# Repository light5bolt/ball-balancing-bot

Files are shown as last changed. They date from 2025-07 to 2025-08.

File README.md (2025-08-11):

# Ball Balancing Bot

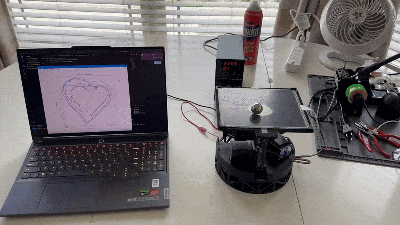
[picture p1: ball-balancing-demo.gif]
Ball Balancing Bot Demo


**A robotics project that uses real-time control and inverse kinematics to keep a ball stable on a movable platform.**

---

## Project Overview

The **Ball Balancing Bot** combines mechanical design, electronics, and control theory to actively stabilize a ball using a 3-degree-of-freedom parallel manipulator.  
It serves as both a hands-on robotics challenge and a learning platform for inverse kinematics, sensor integration, and feedback control.

If you want to see the full build process, circuit assembly, and code integration, check out the **Instructables tutorial**:  
[**DIY Ball Balancer Robot! : 6 Steps with Pictures (with Pictures)**](https://www.instructables.com/Lets-Make-a-Ball-Balancer-Robot/)

---

## Repository Contents

- **`BallBalancingBot/`** – Core control implementation (C++).
- **`CAD Files and STLs/`** – 3D printable and editable CAD files for the mechanical frame.
- **`Python Plotters/`** – Scripts for plotting system performance and visualizing motion data.
- **`Ball Balancing Robot Circuit Documentation.pdf`** – Detailed circuit diagrams and wiring instructions.
- **`Ball Balancing Robot IK Derivation.pdf`** – Full symbolic derivation of the inverse kinematics equations.
- **`circuit_image.png`** – Quick reference circuit schematic.

---

## Features

- Complete inverse kinematics derivation for a 3-RRS parallel manipulator.
- Modular CAD/STL files for easy reproduction and modification.
- Circuit documentation with clear wiring diagrams.
- Python visualization tools for trajectory and control analysis.

---

## Project Structure

ball-balancing-bot/
│
├── BallBalancingBot/ # Core control implementation

├── CAD Files and STLs/ # Mechanical component models

├── Python Plotters/ # Visualization scripts

├── Ball Balancing Robot Circuit Documentation.pdf

├── Ball Balancing Robot IK Derivation.pdf

├── circuit_image.png

└── README.md

---

## License

This work is licensed under the **Creative Commons Attribution-NonCommercial-ShareAlike 4.0 International License**.  
You are free to share and adapt the material for non-commercial purposes, as long as you give appropriate credit and distribute your contributions under the same license.



---

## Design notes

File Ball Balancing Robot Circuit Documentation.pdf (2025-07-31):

# Circuit Documentation

## Summary

This circuit is designed to control multiple bipolar stepper motors using TMC2208 stepper motor drivers, a Teensy 4.0 microcontroller, and a resistive touch screen interface. The circuit is powered by a 48V power supply, which is stepped down to 5V for the Teensy and other components. The TMC2208 drivers are used to control the stepper motors, and the Teensy microcontroller is responsible for sending control signals to the drivers and interfacing with the touch screen.

## Component List

1. TMC2208 Stepper Motor Driver
- Description: A stepper motor driver used to control bipolar stepper motors.
- Pins: GND, VIO, M2B, M2A, M1A, M1B, VM, DIR, STEP, CLK, PDN, NC, MS2, MS1, EN
2. Power Supply
- Description: Provides power to the circuit.
- Pins: +, -
3. Bipolar Stepper Motor (NEMA 17)
- Description: A type of stepper motor used for precise control of motion.
- Pins: A-, A+, B+, B-
4. Electrolytic Capacitor
- Description: Used for filtering and stabilizing voltage.
- Pins: -, +
- Properties: Capacitance: 0.0001 Farads
5. Teensy 4.0 Microcontroller
- Description: A microcontroller used for processing and control tasks.
- Pins: 5V, GND, 3V, 23, 22, 21, 20, 19, 18, 17, 16, 15, 14, 13, 12, 11, 10, 9, 8, 7, 6, 5, 4, 3, 2, 1, 0
6. 48V to 5V Converter
- Description: Steps down voltage from 48V to 5V.
- Pins: out+, out--, in+, in--
7. Rocker Switch
- Description: A switch used to control the power supply.
- Pins: 1, 2
8. Resistive Touch Screen
- Description: A touch screen interface for user input.
- Pins: 1, 2, 3, 4

## Wiring Details

### TMC2208 Stepper Motor Driver

- VM Pin: Connected to the positive terminal of the electrolytic capacitors and the 48V to 5V converter's in+ pin.
- GND Pin: Connected to the negative terminal of the electrolytic capacitors, the 48V to 5V converter's in-- pin, and the Teensy 4.0's GND pin.
- VIO, MS2, MS1 Pins: Connected to the Teensy 4.0's 3V pin.
- EN Pin: Connected to the Teensy 4.0's pin 0.
- STEP Pin: Connected to the Teensy 4.0's pins 1, 3, and 5 for different instances.
- DIR Pin: Connected to the Teensy 4.0's pins 2, 4, and 6 for different instances.

### Power Supply

- + Pin: Connected to the Rocker Switch's pin 2.
- - Pin: Connected to the 48V to 5V converter's in-- pin.

### Bipolar Stepper Motor (NEMA 17)

- A+, A-, B+, B- Pins: Connected to the corresponding M1A, M1B, M2A, M2B pins on the TMC2208 drivers.

### Electrolytic Capacitor

- + Pin: Connected to the VM pin of the TMC2208 drivers and the 48V to 5V converter's in+ pin.
- - Pin: Connected to the GND pin of the TMC2208 drivers and the 48V to 5V converter's in-- pin.

### Teensy 4.0 Microcontroller

- 5V Pin: Connected to the 48V to 5V converter's out+ pin.
- GND Pin: Connected to the 48V to 5V converter's out-- pin and the GND pin of the TMC2208 drivers.
- 3V Pin: Connected to the VIO, MS2, and MS1 pins of the TMC2208 drivers.
- Pins 0-6: Used for control signals to the TMC2208 drivers.

### 48V to 5V Converter

- in+ Pin: Connected to the Rocker Switch's pin 1.
- in-- Pin: Connected to the GND pin of the TMC2208 drivers and the Power Supply's - pin.
- out+ Pin: Connected to the Teensy 4.0's 5V pin.

- out-- Pin: Connected to the Teensy 4.0's GND pin.

### Rocker Switch

- Pin 1: Connected to the 48V to 5V converter's in+ pin.
- Pin 2: Connected to the Power Supply's + pin.

### Resistive Touch Screen

- Pins 1-4: Connected to the Teensy 4.0's pins 14-17 for touch input.

## Code Documentation

Refer to https://github.com/skulkarni3000/ball-balancing-bot

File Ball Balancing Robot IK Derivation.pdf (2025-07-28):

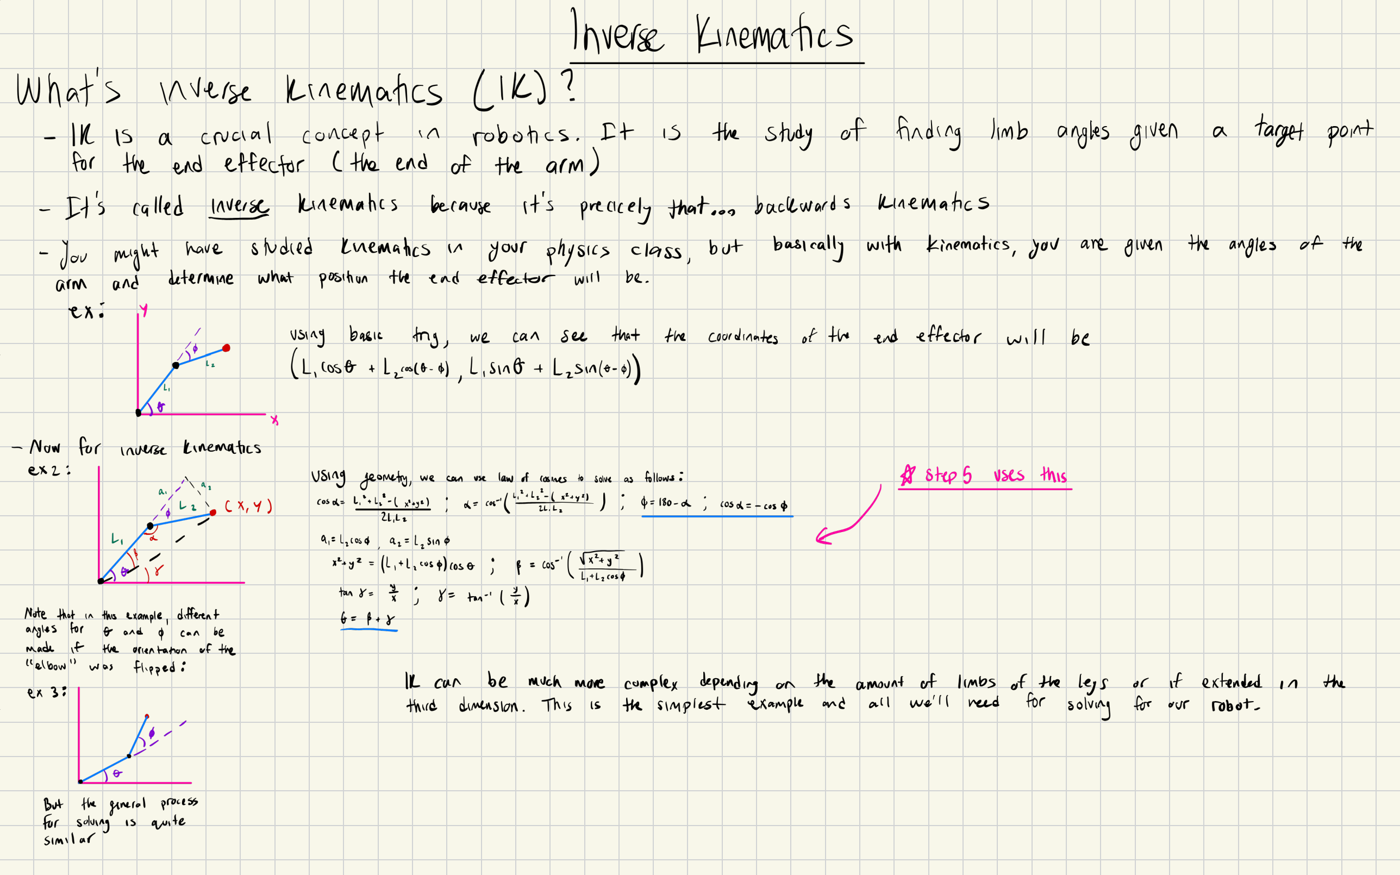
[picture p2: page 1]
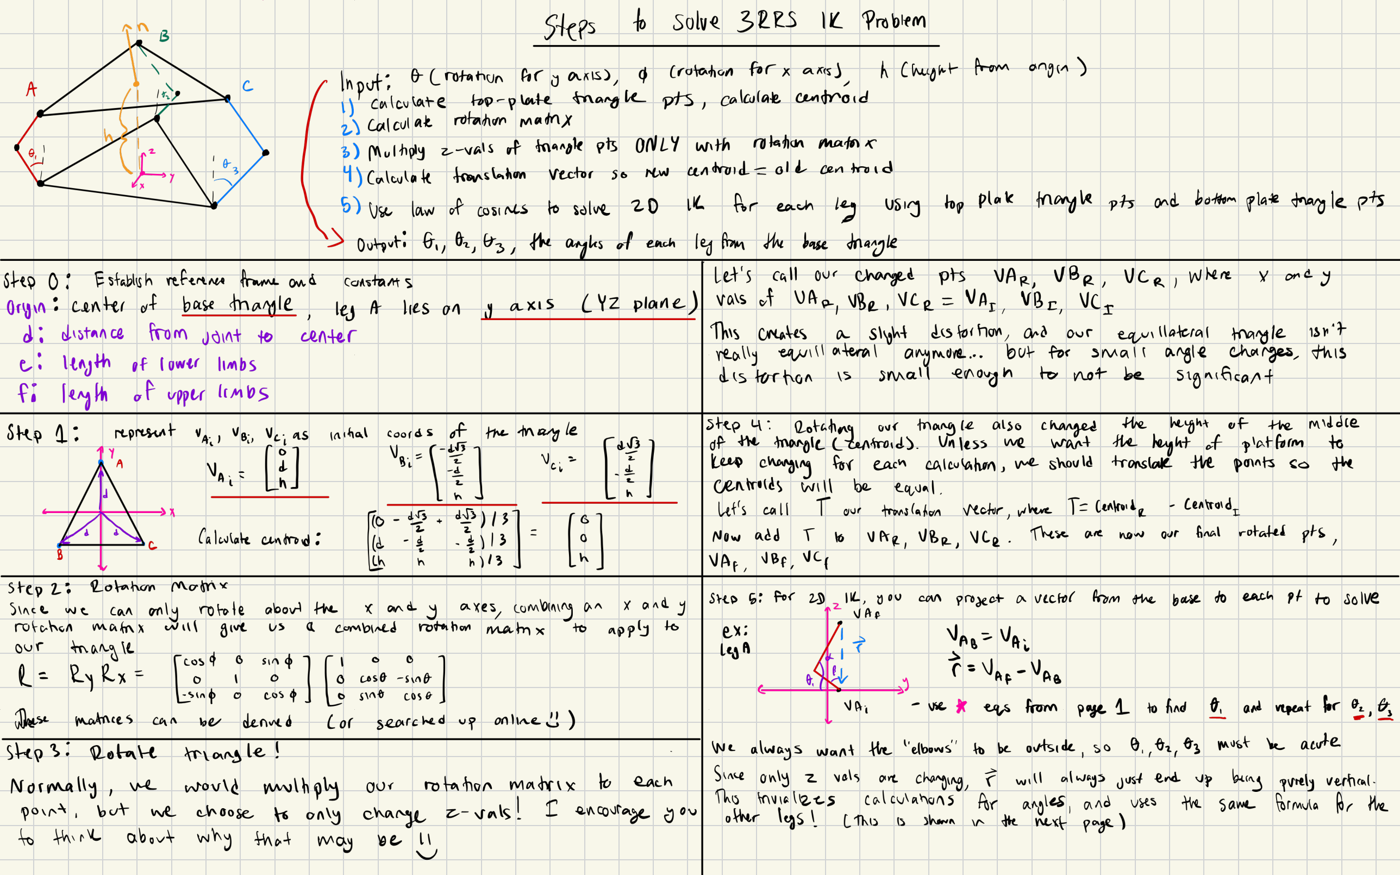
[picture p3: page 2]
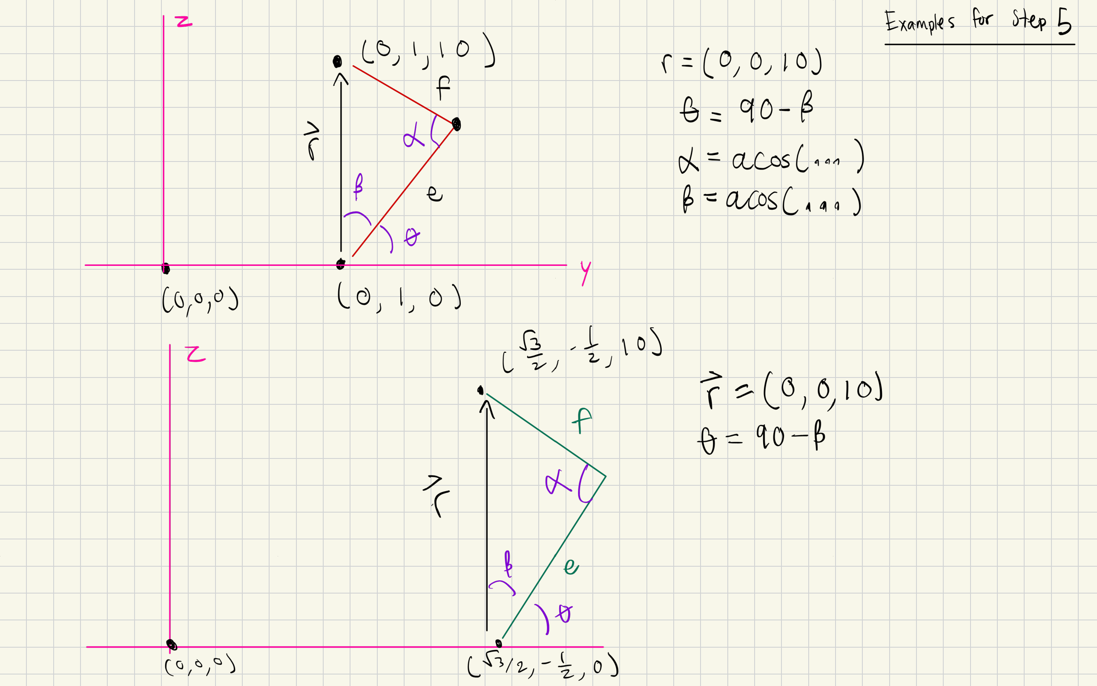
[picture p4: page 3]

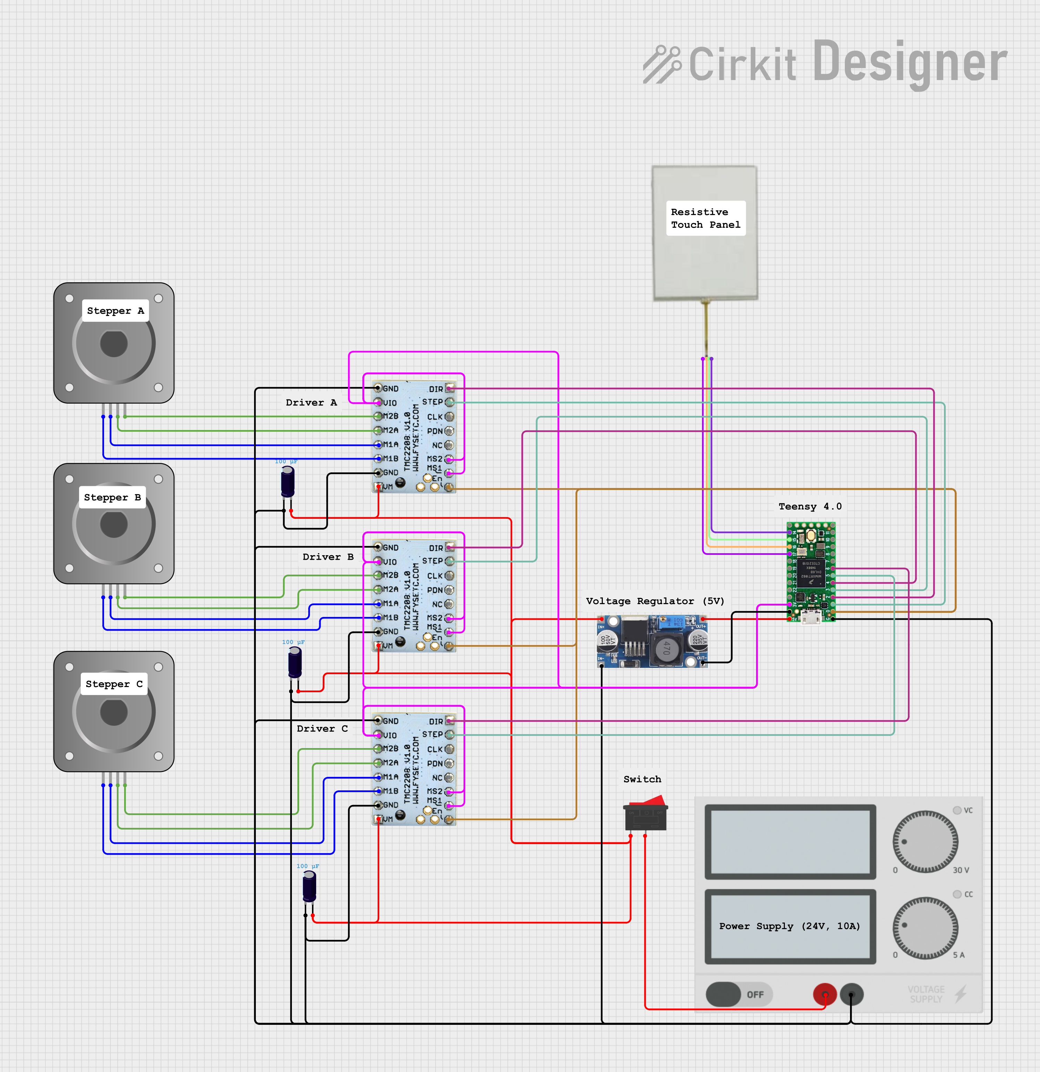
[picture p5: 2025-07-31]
circuit_image.png

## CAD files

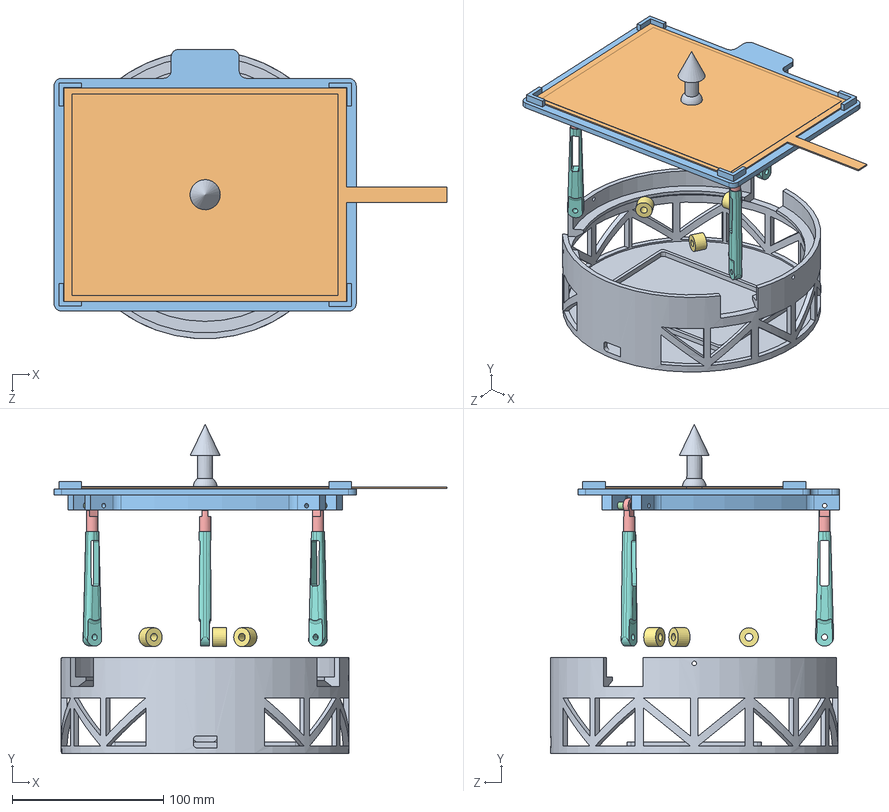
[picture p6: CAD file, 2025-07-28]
CAD Files and STLs/Robot Full Assem.SLDASM
260.0 x 217.9 x 191.5 mm
RobotBase
UpperLimb x 3
Shaft Spacer x 3
TieRod Ball x 3
TieRod Base x 3
M3 Spacer x 6
ScreenPlate
LCD Screen
NormalVector

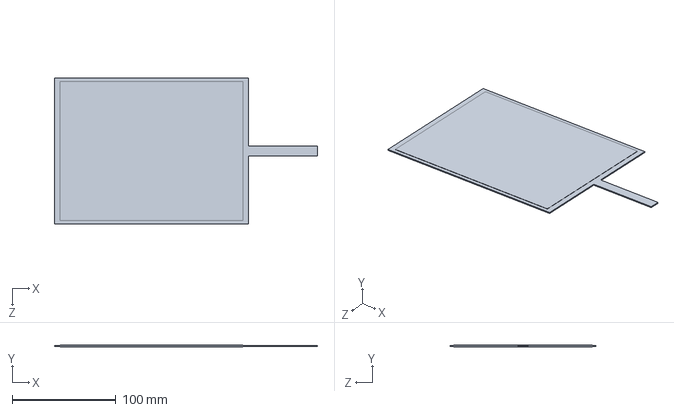
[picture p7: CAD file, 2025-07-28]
CAD Files and STLs/Parts/LCD Screen.SLDPRT
253.5 x 1.58 x 141.0 mm

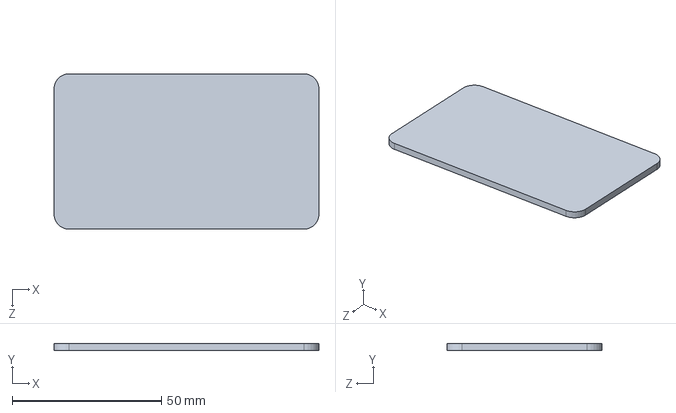
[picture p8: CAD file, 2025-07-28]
CAD Files and STLs/Parts/BreadboardPlaceholder.SLDPRT
88.9 x 2.50 x 52.1 mm

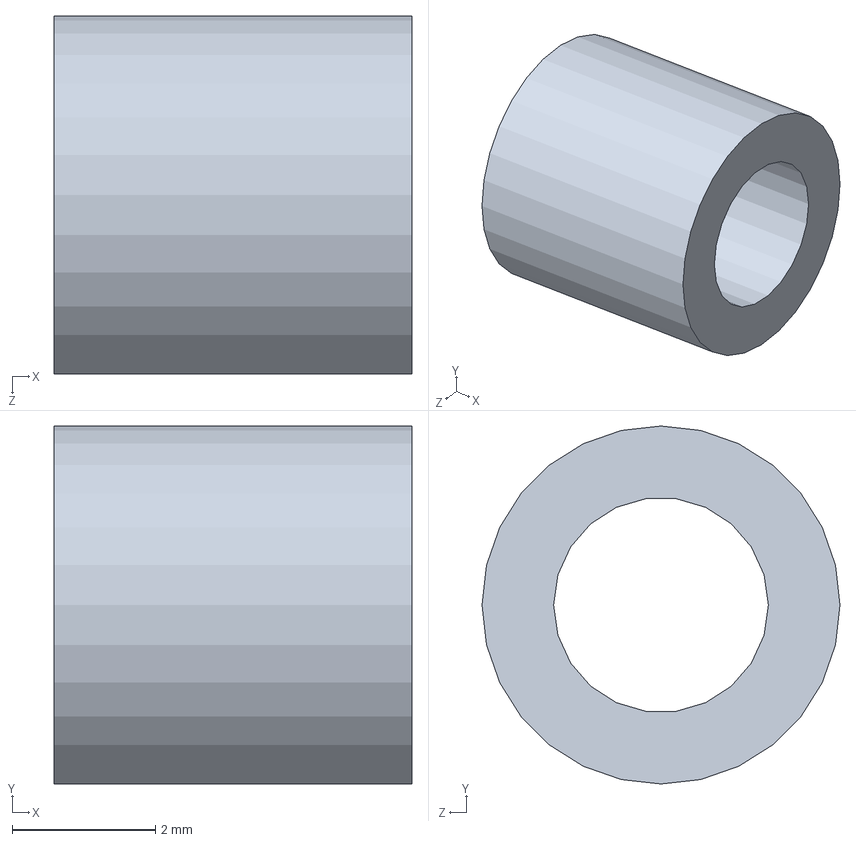
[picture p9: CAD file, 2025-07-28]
CAD Files and STLs/Parts/M3 Spacer.SLDPRT
5.00 x 5.00 x 5.00 mm

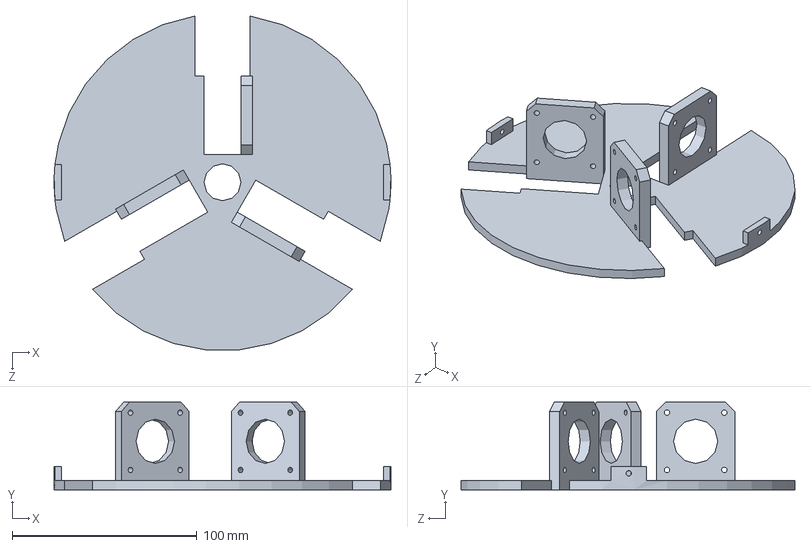
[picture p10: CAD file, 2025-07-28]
CAD Files and STLs/Parts/MotorPlate.SLDPRT
182.3 x 47.5 x 180.6 mm

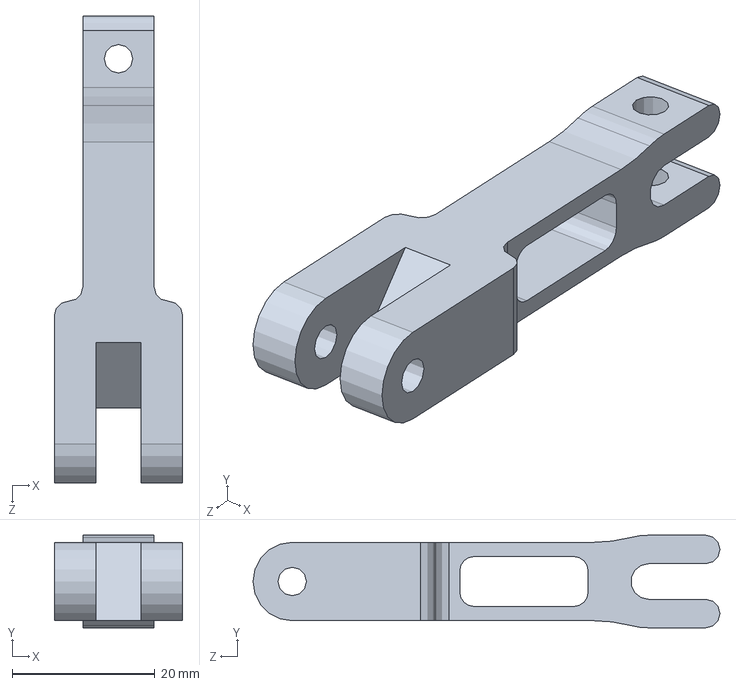
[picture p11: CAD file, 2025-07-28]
CAD Files and STLs/Parts/LowerLimb.SLDPRT
18.0 x 13.0 x 65.5 mm

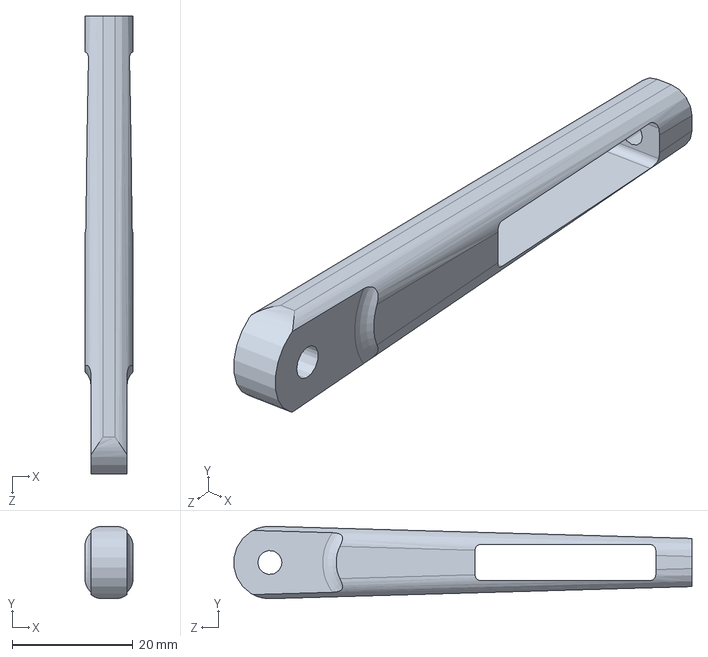
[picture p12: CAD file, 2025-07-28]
CAD Files and STLs/Parts/UpperLimb.SLDPRT
8.00 x 12.0 x 75.9 mm

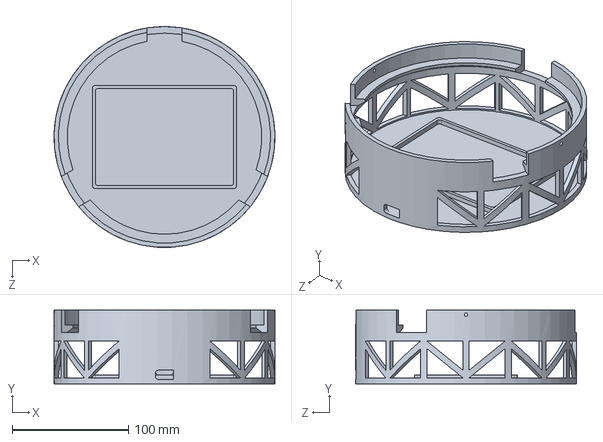
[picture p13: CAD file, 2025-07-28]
CAD Files and STLs/Parts/RobotBase.SLDPRT
190.5 x 63.5 x 190.5 mm

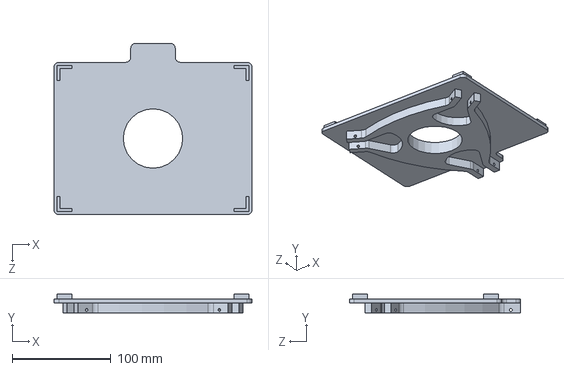
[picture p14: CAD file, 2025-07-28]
CAD Files and STLs/Parts/ScreenPlate.SLDPRT
200.0 x 19.0 x 173.2 mm

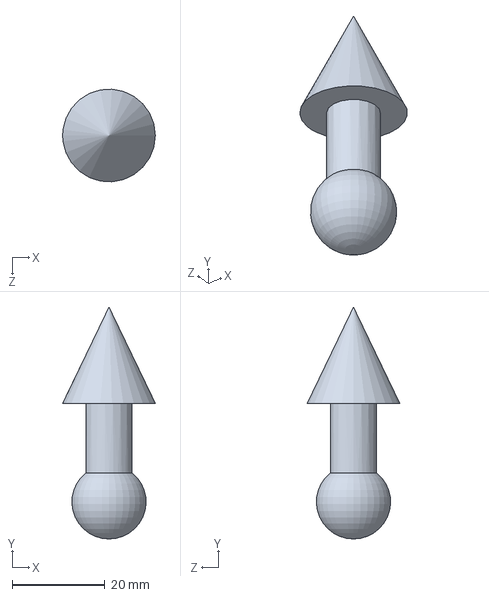
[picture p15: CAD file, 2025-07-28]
CAD Files and STLs/Parts/NormalVector.SLDPRT
20.0 x 50.0 x 20.0 mm

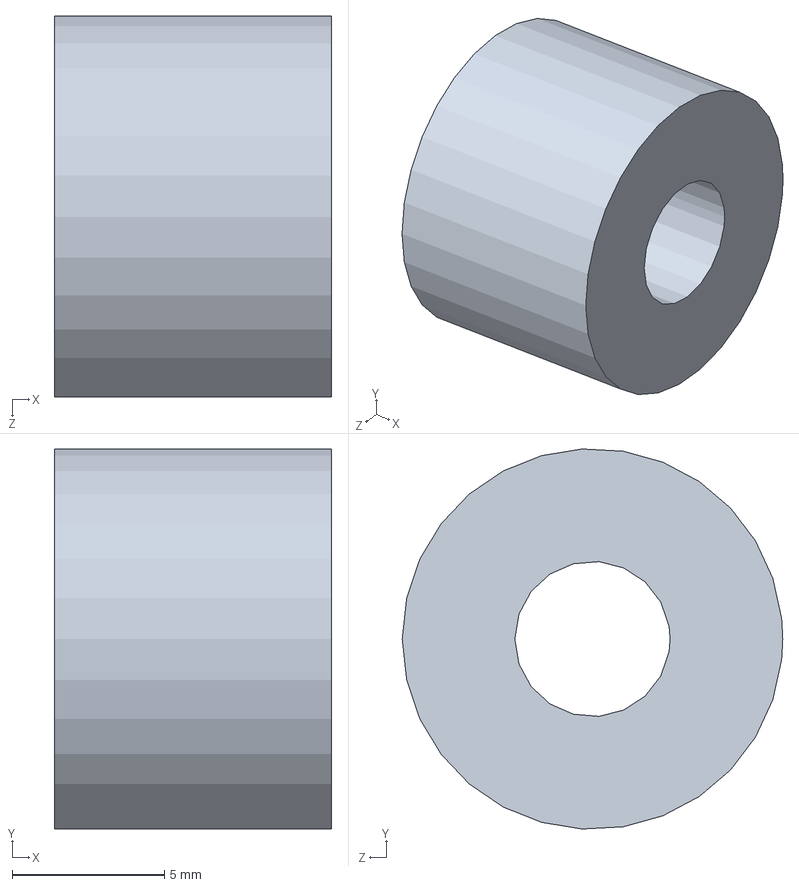
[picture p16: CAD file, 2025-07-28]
CAD Files and STLs/Parts/Shaft Spacer.SLDPRT
9.10 x 12.5 x 12.5 mm

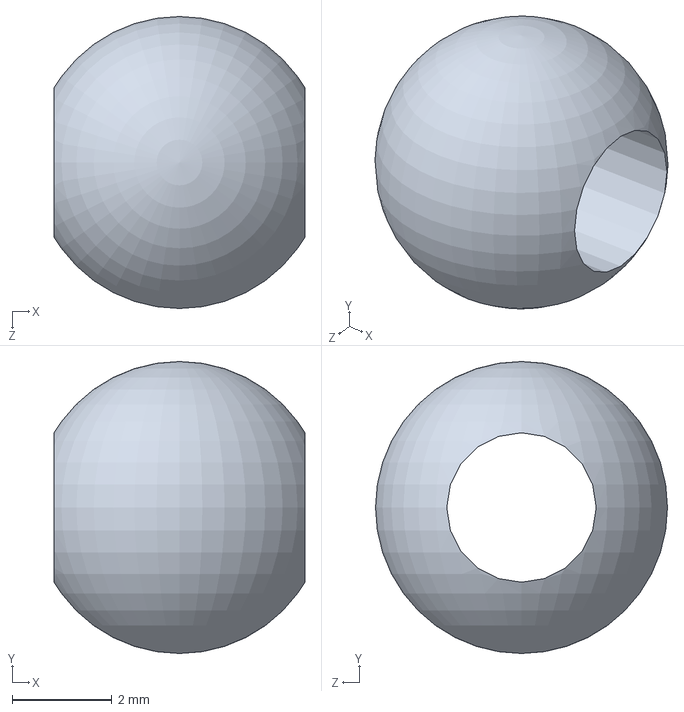
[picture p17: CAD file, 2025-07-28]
CAD Files and STLs/Parts/TieRod Ball.SLDPRT
5.03 x 5.86 x 5.86 mm

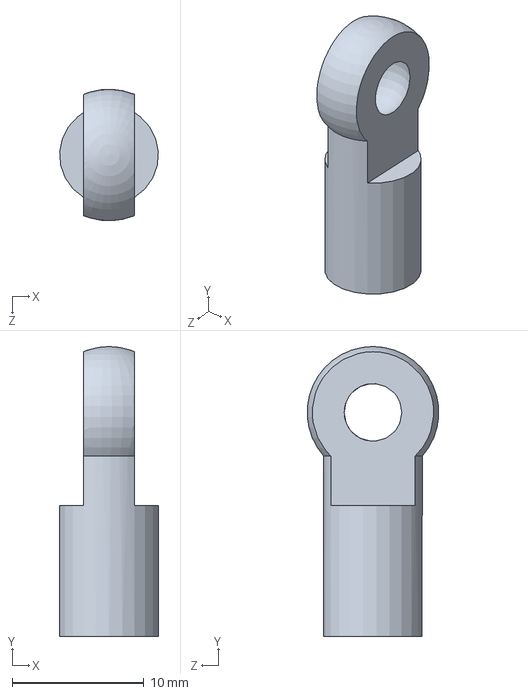
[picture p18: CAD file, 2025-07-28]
CAD Files and STLs/Parts/TieRod Base.SLDPRT
7.48 x 22.0 x 9.97 mm

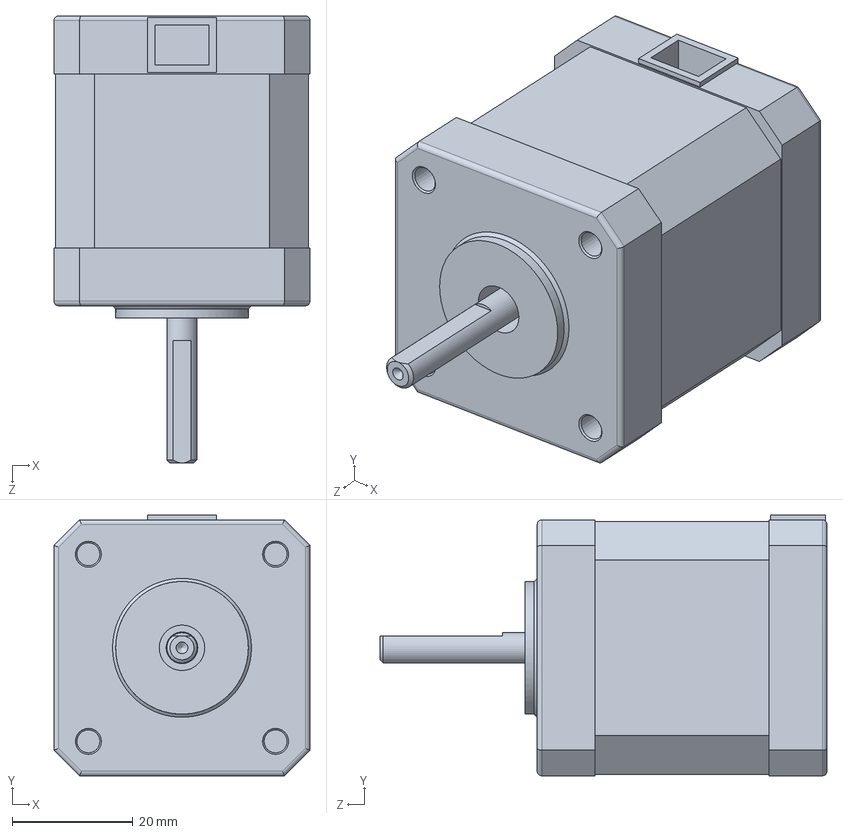
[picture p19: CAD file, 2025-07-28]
CAD Files and STLs/Parts/StepperMotor.SLDPRT
42.4 x 43.2 x 74.0 mm

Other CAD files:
CAD Files and STLs/STLs/LowerLimb.STL
CAD Files and STLs/STLs/MotorPlate.STL
CAD Files and STLs/STLs/RobotBase.STL
CAD Files and STLs/STLs/ScreenPlate.STL
CAD Files and STLs/STLs/ShaftSpacer.STL
CAD Files and STLs/STLs/UpperLimb.STL

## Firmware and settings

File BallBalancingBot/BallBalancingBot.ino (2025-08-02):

#include <Arduino.h>
#include "InverseKinematics.h"
#include "MotorControl.h"
#include "Screen.h"
#include "PIDControllers.h"


// Global variable declaration
bool enable_serial_output = true;

// Function definitions
void muteAllSerialOutput() {
  enable_serial_output = false;
}

void enableAllSerialOutput() {
  enable_serial_output = true;
}


void setup() {
  // Initialization functions
  Serial.begin(115200);
  muteAllSerialOutput();
  if (enable_serial_output) Serial.println("----------------NEW RUN-----------------"); 
  screen_init();
  motor_init();
  home_motors();
  go_home();
  delay(1000);

  // Headers for CSV file reading
  //Serial.println("Time(ms),Ball_X(mm),Ball_Y(mm),Target_X(mm),Target_Y(mm)");
}

void loop() {
  pid_balance(0,0);
  //move_ellipse(30, 20, 20, 4);
  //move_figure8(30, 20, 4);
  //move_square(30, 20, 4);
  //move_heart(40, 20, 4);
}

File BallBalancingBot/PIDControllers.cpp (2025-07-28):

#include <Arduino.h>
#include <math.h>
#include "PIDControllers.h"

extern bool enable_serial_output;

// PID Constants
#define kp .8            //.8
#define ki .2            //.2
#define kd .09           //.09
#define kv 0.05          //.05
#define kp_adj .4        //.4
#define ki_adj .25       //.25
#define kd_adj .23       //.23
#define max_output 83.5  // max X distance away from the center
#define max_angle 12.5   // max tilt angle

//Variables needed for PID control
double error[2] = { 0, 0 }, error_prev[2], integ[2] = { 0, 0 }, deriv[2] = { 0, 0 }, output[2], output_angles[2];
double speed[3] = { 0, 0, 0 }, speed_prev[3];

// variables for velocity damping
double ball_vel[2] = { 0, 0 }, p_prev[2] = { 0, 0 };
double predict_time = 0.3;

//Runs X and Y PID Controllers to balance ball at a specific point.
void pid_balance(double setpoint_x, double setpoint_y) {

  static unsigned long t_prev = 0;              // Records previous time (uses static so the variable gets remembered through each loop iteration)
  static unsigned long last_detected_time = 0;  // Track when ball was last detected
  unsigned long t = millis();                   // Records current time using millis() (which counts total time since the program started)
  double dt = (t - t_prev) / 1000.0;            // Converts milliseconds to seconds

  // Handles first run or unreasonable time gaps
  if (t_prev == 0 || dt > .075) {
    t_prev = t;
    //Serial.println((String) "dt: " + dt + ". Time gap too large or first run. Resetting timing.");
    return;  // Ends function
  }

  // Only runs if minimum sample time has passed (0.01 seconds or 10 milliseconds)
  if (dt >= 0.01) {
    bool detected = check_detected();  //checks if ball is detected
    coords p = get_coords();           // retrieves ball's position


    if (detected) {
      last_detected_time = t;

      // Output data for plotting (every 10th iteration to avoid overwhelming)
      static int plot_counter = 0;
      if (plot_counter % 10 == 0 && !enable_serial_output) {

        // CSV format: Timestamp, Ball_X, Ball_Y, Target_X, Target_Y
        Serial.print(millis());
        Serial.print(",");
        Serial.print(p.x_mm, 3);  // 3 decimal places
        Serial.print(",");
        Serial.print(p.y_mm, 3);
        Serial.print(",");
        Serial.print(setpoint_x, 3);
        Serial.print(",");
        Serial.println(setpoint_y, 3);
      }
      plot_counter++;

      // Calculate velocity
      ball_vel[0] = (p.y_mm - p_prev[0]) / (dt * 50);
      ball_vel[1] = (p.x_mm - p_prev[1]) / (dt * 50);
      p_prev[0] = p.y_mm;
      p_prev[1] = p.x_mm;

      // Calculates PID values and send output to motors
      for (int i = 0; i < 2; i++) {

        error_prev[i] = error[i];
        double error_current = (i == 0) ? (p.y_mm - setpoint_y) : (p.x_mm - setpoint_x);  //Calculates error based on ball position
        double v = constrain(ball_vel[i], -1000, 1000);
        error[i] = error_current;
        integ[i] += error[i] * dt;
        integ[i] = constrain(integ[i], -50, 50);  // Constrains integral values to prevent windup
        deriv[i] = (error[i] - error_prev[i]) / dt;
        deriv[i] = isnan(deriv[i]) || isinf(deriv[i]) ? 0 : deriv[i];  // Simple check to eliminate nonreal or infinite numbers, as derivative is being divided by a number that could be zero

        // Adjusts gain constants if ball is close to target
        if (abs(error[i]) < 25) {
          output[i] = kp_adj * error[i] + ki_adj * integ[i] + kd_adj * deriv[i];
        } else {
          output[i] = kp * error[i] + ki * integ[i] + kd * deriv[i];
        }
        output_angles[i] = constrain(output[i], -max_output, max_output) * (max_angle / max_output);  // scales down PID output and maps it to an angle
      }

      // calculates requires speeds for each motors
      speed_controller(speed);

      // for each calculated PID value, run the move command for 20ms
      unsigned long move_start = millis();
      while (millis() - move_start < 20) {
        move_to_angle(output_angles[0], -output_angles[1], 80, speed);
      }

      // Prints PID angle outputs if desired
      if (enable_serial_output) Serial.println((String) "X angle: " + output_angles[1] + ". Y angle: " + output_angles[0] + ". Speed of motor A: " + speed[0]);
    }

    else {
      // Check if ball has been undetected for 3 seconds (3000 milliseconds)
      if (t - last_detected_time >= 3000) {
        integ[0] = integ[1] = 0;         // Reset integral terms after 3 seconds
        move_to_angle(0, 0, 80, speed);  // Goes back to home
      }

      //waits and checks again if ball is detected (eliminates error from input)
      delay(10);
      detected = check_detected();
      if (!detected) {
        //Serial.println("Ball not detected!");
        return;  // exits current iteration
      }
    }
    t_prev = t;  // resets value of t_prev
  }
}

//uses the PID controller to move the ball to a point for a specified amount of time (in milliseconds)
void move_to_point(double setpoint_x, double setpoint_y, unsigned long delay) {
  unsigned long t_prev = millis();
  if (enable_serial_output) Serial.println((String) "Moving to pt: ( " + setpoint_x + " , " + setpoint_y + " )");
  while (millis() - t_prev < delay) {
    pid_balance(setpoint_x, setpoint_y);
  }
}

// moves in a line pattern. rx and ry are distance from endpoint to center (0-80). speed: (10-50 ms). repeat: num of times (0 = infinite loop)
void move_line(double rx, double ry, double speed, int repeat) {
  int cycles = (repeat == 0) ? 9999 : repeat;

  move_to_point(-rx, -ry, 2000);  // moves to start point
  // move from points (-rx, -ry) to (rx, ry)
  for (int i = 0; i < cycles; i++) {
    // calculate amount of intermediate steps
    double steps = 100;
    double steps_x = (2 * rx) / steps;
    double steps_y = (2 * ry) / steps;

    // forward direction
    for (int j = 0; j <= steps; j++) {
      double x = -rx + (j * steps_x);
      double y = -ry + (j * steps_y);
      move_to_point(x, y, speed);
    }

    // backwards direction
    for (int j = steps; j >= 0; j--) {
      double x = -rx + (j * steps_x);
      double y = -ry + (j * steps_y);
      move_to_point(x, y, speed);
    }
  }
  Serial.println("---------------Line pattern finished--------------");
}
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

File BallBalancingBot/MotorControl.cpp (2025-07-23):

#include "MotorControl.h"

#define ANGLE_TO_ORIGIN_A 71     // angle offset
#define ANGLE_TO_ORIGIN_B 66.75  // angle offset
#define ANGLE_TO_ORIGIN_C 61.95  // angle offset
#define ENA 0                    // ENA pin
#define h0 87                    // height of platform when motors are at zero position
#define ks 100.0                 // a constant to change our proportional speed function

// setup for steppers
AccelStepper motorA(1, 3, 2);  //(driver type, STEP, DIR) Driver A
AccelStepper motorB(1, 5, 4);  //(driver type, STEP, DIR) Driver B
AccelStepper motorC(1, 7, 6);  //(driver type, STEP, DIR) Driver C
MultiStepper motors;           // Create instance of MultiStepper

long int pos[3];              // stores positions of stepper motors
extern double speed[3];       // an initialization of the stepper motor speeds
extern double speed_prev[3];  // an array to store previous speeds which we use later to change speed proportionally

//initializes motors by adding them in multistepper class
void motor_init() {
  motors.addStepper(motorA);
  motors.addStepper(motorB);
  motors.addStepper(motorC);
  pinMode(ENA, OUTPUT);
  digitalWrite(ENA, HIGH);
  delay(2000);
  digitalWrite(ENA, LOW);
}

// angle in degrees to the nearest step (rounds up)
long int angle_to_steps(double angle) {
  return round((3200 / 360) * angle);
}

//steps to nearest angle (as a decimal)
double steps_to_angle(int steps) {
  return (360 / 3200) * steps;
}

//moves motors to position where bottom leg is parallel to the ground. this is the zero position
void home_motors() {
  motorA.setMaxSpeed(1000);
  motorB.setMaxSpeed(1000);
  motorC.setMaxSpeed(1000);

  pos[0] = angle_to_steps(ANGLE_TO_ORIGIN_A);
  pos[1] = angle_to_steps(ANGLE_TO_ORIGIN_B);
  pos[2] = angle_to_steps(ANGLE_TO_ORIGIN_C);

  //calculates position and moves all motors to the zero position
  motors.moveTo(pos);
  motors.runSpeedToPosition();

  //makes the new point the origin (zero position)
  motorA.setCurrentPosition(0);
  motorB.setCurrentPosition(0);
  motorC.setCurrentPosition(0);

  //Serial.println("Motors to zero position");
}

//goes to zero position (home). requires home_motors first.
void go_home() {
  for (int i = 0; i < 3; i++) pos[i] = 0;
  motors.moveTo(pos);
  motors.runSpeedToPosition();
}

// calculates positions to move to a specific angle, but only moves at most one step per call.
void move_to_angle(double theta_deg, double phi_deg, double h, double speed[3]) {

  //uses get_angles function to get positions required to move to position
  CalculatedAngles result = get_angles(theta_deg, phi_deg, h);
  pos[0] = angle_to_steps(result.thetaA);
  pos[1] = angle_to_steps(result.thetaB);
  pos[2] = angle_to_steps(result.thetaC);

  //sets max speed
  motorA.setMaxSpeed(speed[0]);
  motorB.setMaxSpeed(speed[1]);
  motorC.setMaxSpeed(speed[2]);

  //sets acceleration proportional to a calculated speed
  motorA.setAcceleration(speed[0] * 50);
  motorB.setAcceleration(speed[1] * 50);
  motorC.setAcceleration(speed[2] * 50);

  //calculates speed to each motor gets to target position at the same time
  motors.moveTo(pos);
  for (int i = 0; i < 10; i++) {
    if (motors.run()) break;  // Stop if all motors reached target
  }
}

//Calculates proportional motor speeds for all three motors whenever function gets called.
void speed_controller(double speed[3]) {
  static double current_pos[3];  // Variable for current positions

  for (int i = 0; i < 3; i++) {
    speed_prev[i] = speed[i];
    current_pos[i] = (i == 0) * motorA.currentPosition() + (i == 1) * motorB.currentPosition() + (i == 2) * motorC.currentPosition();  // Finds current position of motor
    speed[i] = abs(current_pos[i] - pos[i]) * ks;                                                                                      // Position error * speed gain
    speed[i] = constrain(speed[i], speed_prev[i] - 300, speed_prev[i] + 300);                                                          // Constrains speed so there aren't any sudden jumps. Essentially substituting for our D term in PID.
    speed[i] = constrain(speed[i], 0, 1300);
  }
}

// Debugger function to test motor speeds
void test_motor_speed() {
  motorA.setMaxSpeed(4000);
  motorA.setAcceleration(10000);
  motorA.moveTo(500);  // Move 1000 steps

  unsigned long start = millis();
  while (motorA.distanceToGo() != 0) {
    motorA.run();
  }
  unsigned long duration = millis() - start;

  Serial.println("Time to move 500 steps: " + String(duration) + "ms");
  Serial.println("Actual speed: " + String(500.0 / (duration / 500.0)) + " steps/sec");
}

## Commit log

2025-07-23 created python script for ball plotting
    [data.csv]
2025-07-23 created real time plotter and formatted arduino code
2025-07-28 reorganized and added CAD files
    [BreadboardPlaceholder.SLDPRT, LCD Screen.SLDPRT, LowerLimb.SLDPRT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]
2025-07-31 added circuit documentation
